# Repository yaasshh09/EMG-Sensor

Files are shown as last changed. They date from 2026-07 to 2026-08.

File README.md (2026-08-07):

## System Overview

The MyoRead is an EMG sensor made up of a four-stage analog circuit that picks up the tiny electrical signals your muscles give off when they contract and cleans them up enough for a computer to read. It's built around the cheap, everyday LM358P op-amp to keep costs down.

```
Forearm electrodes 
      |
      v
[Stage 1] Instrumentation Amplifier   -- 101x gain, rejects common-mode noise
      |
      v
[Stage 2] Twin-T 50 Hz Notch Filter   -- kills UAE mains hum
      |
      v
[Stage 3] Sallen-Key Bandpass 20-500 Hz -- isolates EMG band
      |
      v
[Stage 4] Half-wave rectifier + RC envelope (tau = 47 ms)
```
<p align="center">
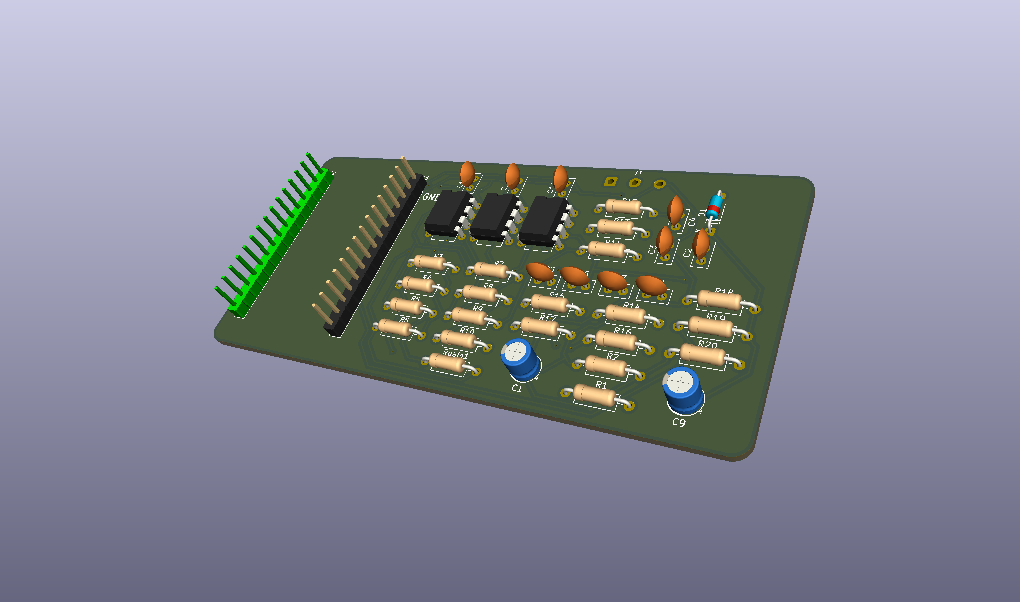
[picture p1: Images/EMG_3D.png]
3D
  
</p>
<p align="center">
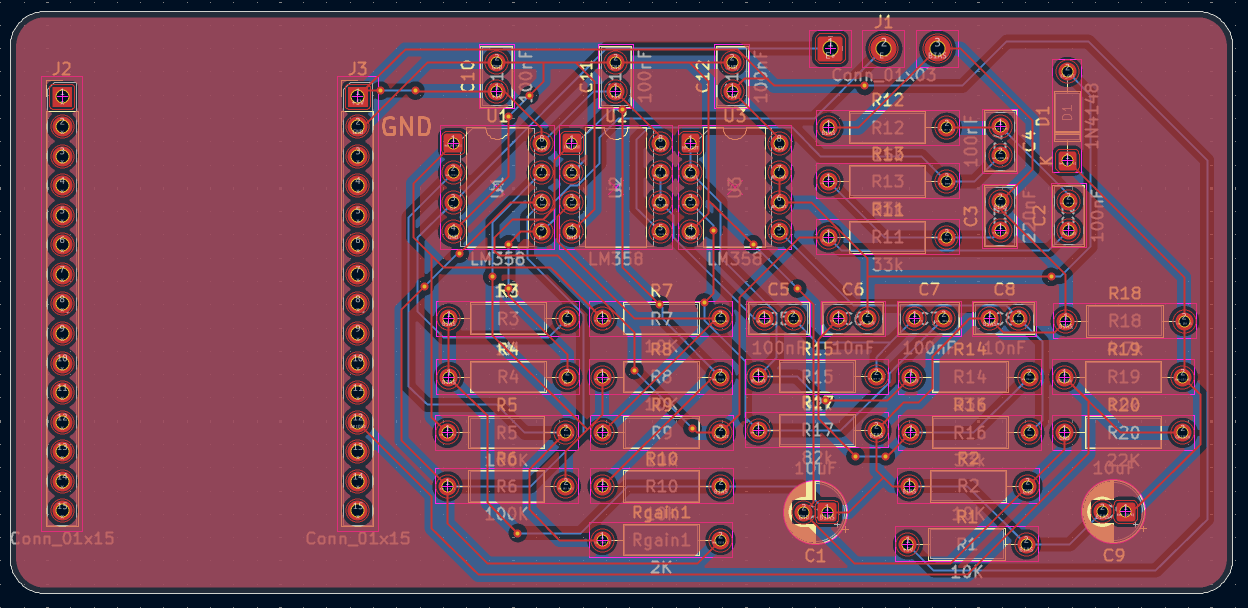
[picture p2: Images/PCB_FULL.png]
FULL
  
</p>
<p align="center">
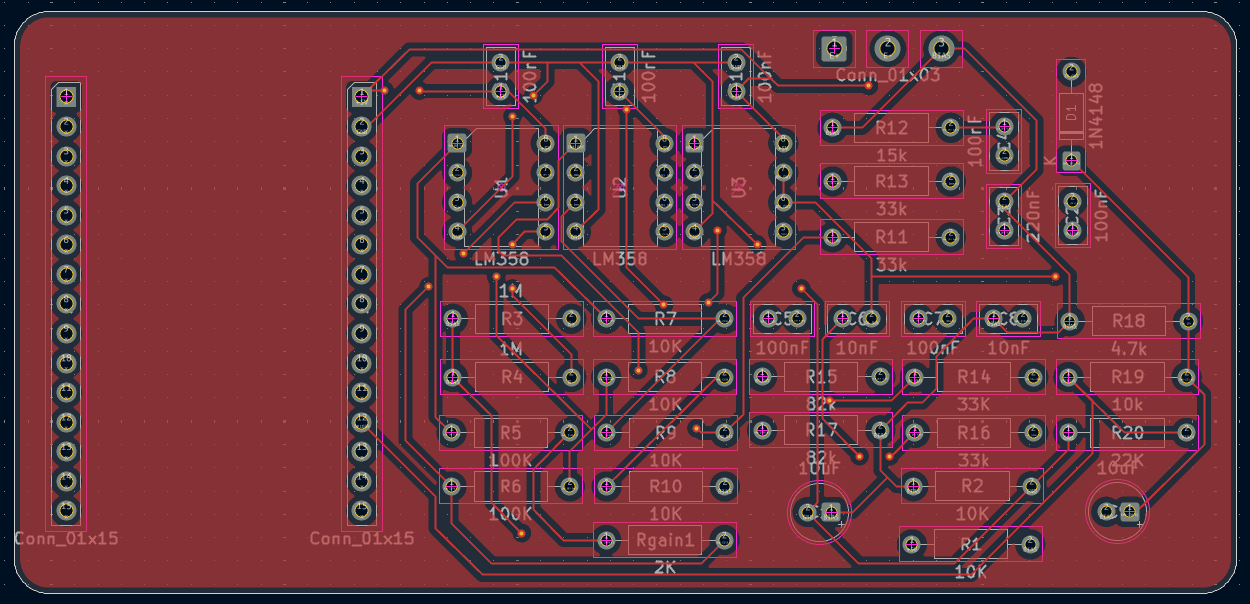
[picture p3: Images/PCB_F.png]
F
  
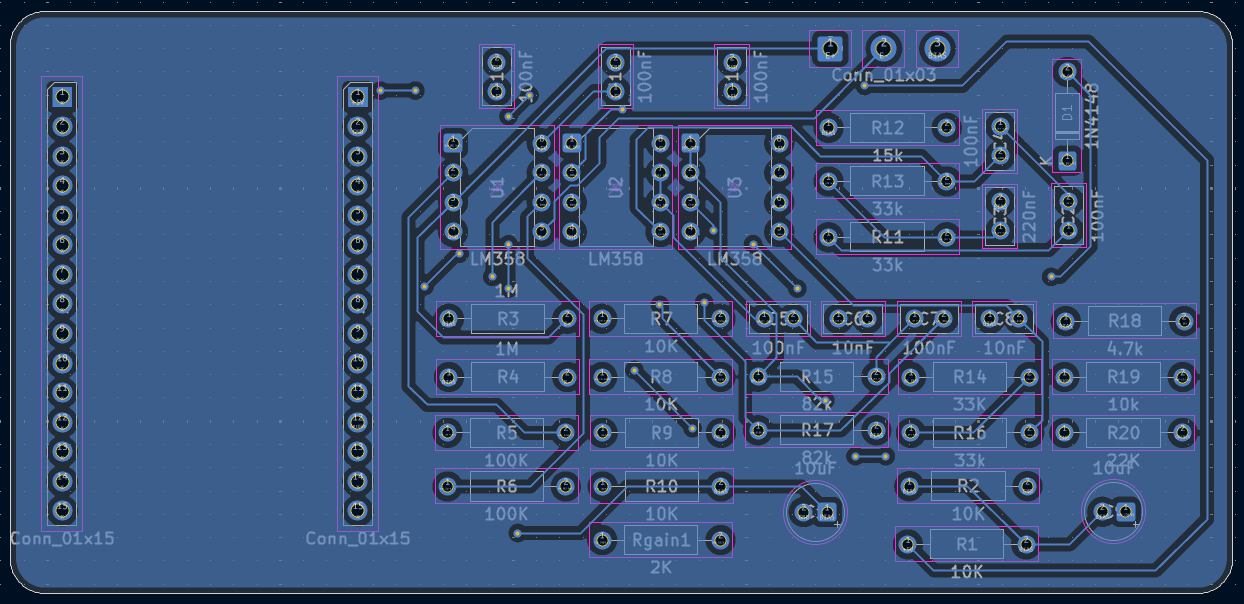
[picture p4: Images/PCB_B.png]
B
 
</p>

## Signal Chain

All op-amp stages use the **LM358P** (DIP-8, single supply 5 V).

The LM358P output swings only 0.05 V to 3.5 V on a 5 V supply. A 2.5 V DC bias is applied at every stage input so the AC signal can swing symmetrically without clipping.

### Stage 0 -- Bias circuit

Two matched 10 kohm resistors from 5 V to GND. Midpoint = 2.5 V.

```
V_bias = 5V x R2 / (R1 + R2) = 5V x 10k / 20k = 2.5 V
```
<p>
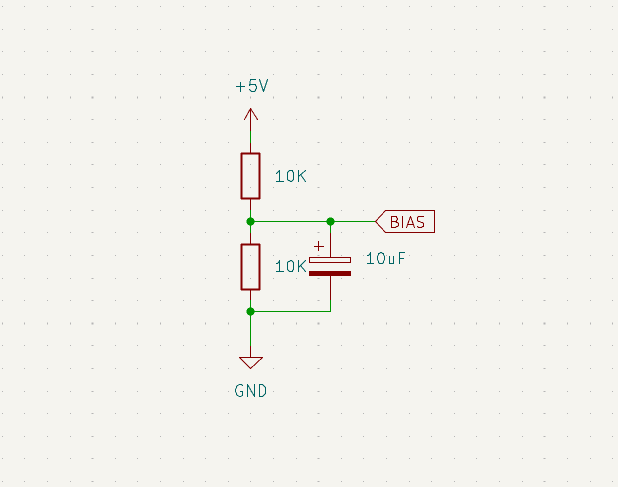
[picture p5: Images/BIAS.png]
   
</p>

### Stage 1 - 3-op-amp instrumentation amplifier

```
Gain = 1 + (2 x Rf / Rg) = 1 + (2 x 100k / 2k) = 101x
```

- Rf = 100 kohm x2 (feedback around OA1, OA2)
- Rg = 2 kohm (single resistor between OA1 IN- and OA2 IN-)
- OA3 difference amplifier: 4 matched 10 kohm resistors

CMRR depends on matching the four OA3 resistors. Select four from the kit using a multimeter: target within 1% of each other.

<p>
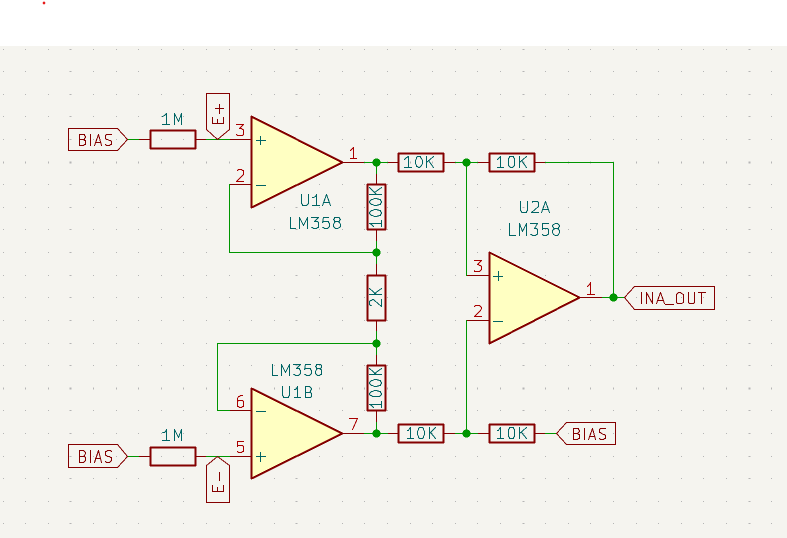
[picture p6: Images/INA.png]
   
</p>

### Stage 2 - Twin-T 50 Hz notch filter

```
f_notch = 1 / (2pi x R x C)
R = 1 / (2pi x 50 x 100nF) = 31.8 kohm --> 33 kohm (E24 standard)
Centre resistor: R/2 = 15 kohm
Centre capacitor: 2C = 220 nF
Actual f_notch with 33 kohm: 48.2 Hz -- effective against 50 Hz hum
```

Followed by a unity-gain op-amp buffer to restore drive capability.

<p>
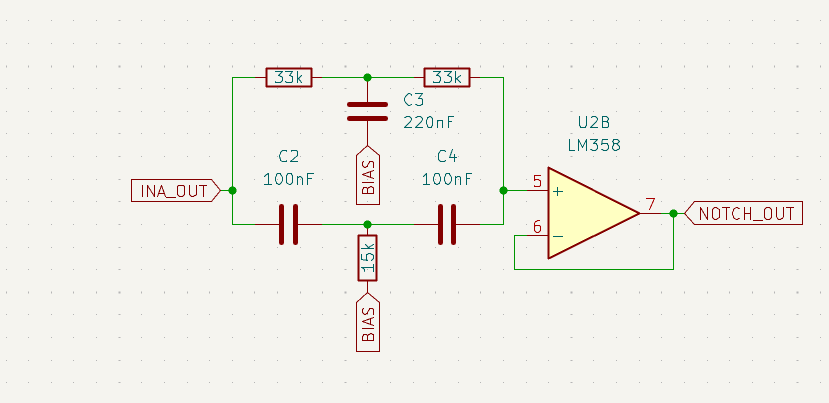
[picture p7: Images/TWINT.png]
   
</p>

### Stage 3 - Sallen-Key bandpass 20-500 Hz

High-pass (20 Hz):
```
C = 100 nF
R = 1 / (2pi x 20 x 100nF) = 79.6 kohm --> 82 kohm
Actual cutoff: 19.4 Hz
```

Low-pass (500 Hz):
```
C = 10 nF
R = 1 / (2pi x 500 x 10nF) = 31.8 kohm --> 33 kohm
Actual cutoff: 482 Hz
```

<p>
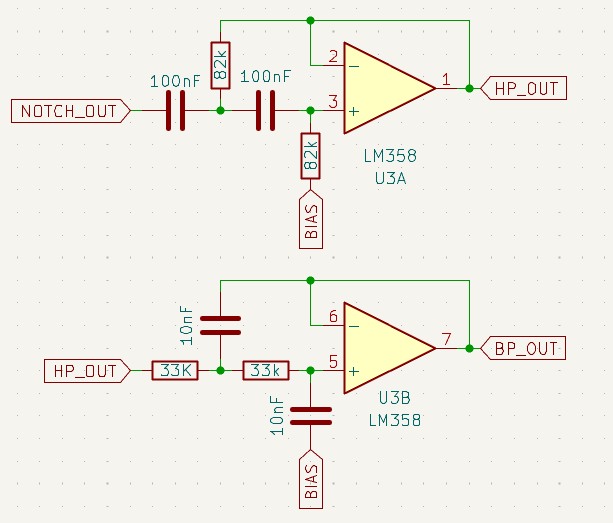
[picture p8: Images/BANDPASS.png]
   
</p>

### Stage 4 - Envelope detector

```
Half-wave rectifier: 1N4148 signal diode (stripe = cathode, faces output)
RC smoother: R = 4.7 kohm, C = 10 uF electrolytic
tau = R x C = 4700 x 0.00001 = 47 ms

Constraint: 1/500Hz = 2ms << tau << 1/20Hz = 50ms  (satisfied)
```
<p>
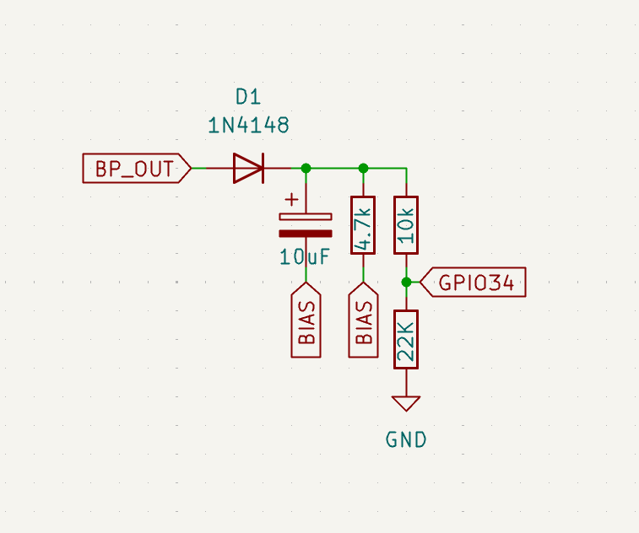
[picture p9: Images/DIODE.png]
   
</p>

The output is a slowly-varying DC voltage proportional to muscle activation level. This feeds directly into your  microcontroller.

## Electrode placement

```
FOREARM (palm facing up, elbow left, wrist right)

+------------------------------------------+
|  ELBOW <----------------------- WRIST    |
|                                          |
|  [IN+]  [IN-]                   [REF]    |
|  2-3 cm apart, over muscle belly  bony   |
|  (inner forearm, palm side)       bump   |
+------------------------------------------+
```

- IN+ and IN- over the forearm flexor muscle belly, 2-3 cm apart along the muscle fibre direction
- REF on the bony wrist prominence (styloid process) -- no muscle underneath, picks up noise only

Skin prep: alcohol wipe, apply conductive gel under each pad. Target skin impedance below 10 kohm between electrodes.

## Bill Of Materials

| Component | Manufacturer Part Number | Description | Quantity | Unit Price | Total Price |
|---|---|---|---:|---:|---:|
| 10 kΩ Resistor | MFR-25FRF52-10K | RES 10K OHM 1% 1/4W AXIAL | 10 | $0.042 | $0.42 |
| 33 kΩ Resistor | MFR-25FTE52-33K | RES 33K OHM 1% 1/4W AXIAL | 10 | $0.042 | $0.42 |
| 1 MΩ Resistor | MFR-25FRF52-1M | RES 1M OHM 1% 1/4W AXIAL | 2 | $0.100 | $0.20 |
| 100 kΩ Resistor | MFR-25FBF52-100K | RES 100K OHM 1% 1/4W AXIAL | 2 | $0.100 | $0.20 |
| 82 kΩ Resistor | MFR-25FBF52-82K | RES 82K OHM 1% 1/4W AXIAL | 2 | $0.100 | $0.20 |
| 15 kΩ Resistor | MFR-25FBF52-15K | RES 15K OHM 1% 1/4W AXIAL | 1 | $0.100 | $0.10 |
| 4.7 kΩ Resistor | MFR-25FTE52-4K7 | RES 4.7K OHM 1% 1/4W AXIAL | 1 | $0.100 | $0.10 |
| 22 kΩ Resistor | MFR-25FTE52-22K | RES 22K OHM 1% 1/4W AXIAL | 1 | $0.100 | $0.10 |
| Signal Diode | 1N4148 | DIODE STANDARD 100V 200MA DO35 | 1 | $0.100 | $0.10 |
| Operational Amplifier | LM358P | IC OPAMP GP 2 CIRCUIT 8DIP | 3 | $0.330 | $0.99 |
| 2 kΩ Resistor | MFR-25FBF52-2K | RES 2K OHM 1% 1/4W AXIAL | 1 | $0.100 | $0.10 |
| 100 nF Ceramic Capacitor | K104K15X7RF5TL2 | CAP CER 0.1UF 50V X7R RADIAL | 10 | $0.167 | $1.67 |
| 10 nF Ceramic Capacitor | A103K15X7RF5TAA | CAP CER 10000PF 50V X7R AXIAL | 2 | $0.260 | $0.52 |
| 10 µF Electrolytic Capacitor | 50YXJ10M5X11 | CAP ALUM 10UF 20% 50V RADIAL TH | 2 | $0.320 | $0.64 |
| 220 nF Ceramic Capacitor | FG14X7R1H224KNT00 | CAP CER 0.22UF 50V X7R RADIAL | 1 | $0.280 | $0.28 |

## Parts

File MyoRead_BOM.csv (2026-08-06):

Index | Manufacturer Part Number | Manufacturer Name | Description | Lead Time | Availability | Stock Status | Attrition % | Requested Quantity 1 | Pack Quantity 1 | Pack Type 1 | Digi-Key Part Number 1 | Unit Price 1 | Extended Price 1 | Minimum Order Quantity 1 | Customer Reference | Requested Part Number | Lead Weeks | Datasheet | Reference Designator | US Import Tariff | Note | Part Status | RoHS Status | REACH Status | Moisture Sensitivity Level (MSL) | ECCN | HTSUS | Country of Origin | Environmental Information | Original Part numbers | Unit of Measure | Image | Product Notes
1 | MFR-25FRF52-10K | YAGEO | RES 10K OHM 1% 1/4W AXIAL |  | 197,132 | In Stock |  | 10 | 10 | Cut Tape (CT) | 13-MFR-25FRF52-10KCT-ND | 0.04200 | $0.42 | 1 |  | 13-MFR-25FRF52-10KCT-ND | 18 | https://yageogroup.com/content/Resource%20Library/Datasheet/YAGEO-MFR_DATASHEET.pdf |  | May apply on shipments to the U.S. |  | Active | ROHS3 Compliant | REACH Unaffected | Not Applicable | EAR99 | 8533.21.0090 | Taiwan |  | 13-MFR-25FRF52-10KCT-ND | Each | https://mm.digikey.com/Volume0/opasdata/d220001/derivates/6/002/365/910/MFR-25FRF52-10K_web%28640x640%29.jpg
2 | MFR-25FTE52-33K | YAGEO | RES 33K OHM 1% 1/4W AXIAL |  | 4,576 | In Stock |  | 10 | 10 | Cut Tape (CT) | 13-MFR-25FTE52-33KCT-ND | 0.04200 | $0.42 | 1 |  | 13-MFR-25FTE52-33KCT-ND | 18 | https://yageogroup.com/content/Resource%20Library/Datasheet/YAGEO-MFR_DATASHEET.pdf |  | May apply on shipments to the U.S. |  | Active | ROHS3 Compliant | REACH Unaffected | Not Applicable | EAR99 | 8533.21.0090 | Taiwan |  | 13-MFR-25FTE52-33KCT-ND | Each | https://mm.digikey.com/Volume0/opasdata/d220001/medias/images/2467/33k-Ohm-Axial-1%25-MFR.jpg
3 | MFR-25FRF52-1M | YAGEO | RES 1M OHM 1% 1/4W AXIAL |  | 10,756 | In Stock |  | 2 | 2 | Cut Tape (CT) | 13-MFR-25FRF52-1MCT-ND | 0.10000 | $0.20 | 1 |  | 13-MFR-25FRF52-1MCT-ND | 18 | https://yageogroup.com/content/Resource%20Library/Datasheet/YAGEO-MFR_DATASHEET.pdf |  | May apply on shipments to the U.S. |  | Active | ROHS3 Compliant | REACH Unaffected | Not Applicable | EAR99 | 8533.21.0090 | Taiwan |  | 13-MFR-25FRF52-1MCT-ND | Each | https://mm.digikey.com/Volume0/opasdata/d220001/derivates/6/002/449/103/MFR-25FRF52-1M_web%28640x640%29.jpg
4 | MFR-25FBF52-100K | YAGEO | RES 100K OHM 1% 1/4W AXIAL |  | 28,752 | In Stock |  | 2 | 2 | Bulk | 100KXBK-ND | 0.10000 | $0.20 | 1 |  | 100KXBK-ND | 18 | https://yageogroup.com/content/Resource%20Library/Datasheet/YAGEO-MFR_DATASHEET.pdf |  | May apply on shipments to the U.S. |  | Active | ROHS3 Compliant | REACH Unaffected | Not Applicable | EAR99 | 8533.21.0090 | China |  | 100KXBK-ND | Each | https://mm.digikey.com/Volume0/opasdata/d220001/derivates/6/002/475/045/MFR-25FRF52-100K_web%28640x640%29.jpg
5 | MFR-25FBF52-82K | YAGEO | RES 82K OHM 1% 1/4W AXIAL |  | 12,381 | In Stock |  | 2 | 2 | Bulk | 13-MFR-25FBF52-82K-ND | 0.10000 | $0.20 | 1 |  | 13-MFR-25FBF52-82K-ND | 18 | https://yageogroup.com/content/Resource%20Library/Datasheet/YAGEO-MFR_DATASHEET.pdf |  | N/A |  | Active | ROHS3 Compliant | REACH Unaffected | Not Applicable | EAR99 | 8533.21.0090 | Taiwan |  | 13-MFR-25FBF52-82K-ND | Each | https://mm.digikey.com/Volume0/opasdata/d220001/medias/images/2460/82k-Ohm-Axial-1%25-MFR.jpg
6 | MFR-25FBF52-15K | YAGEO | RES 15K OHM 1% 1/4W AXIAL | 1 past due; estimated in-stock on 20-Jul-2026 | 0 | Normally Stocking |  | 1 | 1 | Bulk | 15.0KXBK-ND | 0.10000 | $0.10 | 1 |  | 15.0KXBK-ND | 18 | https://yageogroup.com/content/Resource%20Library/Datasheet/YAGEO-MFR_DATASHEET.pdf |  | May apply on shipments to the U.S. |  | Active | ROHS3 Compliant | REACH Unaffected | Not Applicable | EAR99 | 8533.21.0090 | China |  | 15.0KXBK-ND | Each | https://mm.digikey.com/Volume0/opasdata/d220001/derivates/6/002/233/244/MFR-25FRF52-15K_web%28640x640%29.jpg
7 | MFR-25FTE52-4K7 | YAGEO | RES 4.7K OHM 1% 1/4W AXIAL |  | 3,565 | In Stock |  | 1 | 1 | Cut Tape (CT) | 13-MFR-25FTE52-4K7CT-ND | 0.10000 | $0.10 | 1 |  | 13-MFR-25FTE52-4K7CT-ND | 18 | https://yageogroup.com/content/Resource%20Library/Datasheet/YAGEO-MFR_DATASHEET.pdf |  | May apply on shipments to the U.S. |  | Active | ROHS3 Compliant | REACH Unaffected | Not Applicable | EAR99 | 8533.21.0090 | Taiwan |  | 13-MFR-25FTE52-4K7CT-ND | Each | https://mm.digikey.com/Volume0/opasdata/d220001/derivates/6/002/645/569/4%2C7k-Ohm-Axial-1%25-MFR_web%28640x640%29.jpg
8 | MFR-25FTE52-22K | YAGEO | RES 22K OHM 1% 1/4W AXIAL |  | 502 | In Stock |  | 1 | 1 | Cut Tape (CT) | 13-MFR-25FTE52-22KCT-ND | 0.10000 | $0.10 | 1 |  | 13-MFR-25FTE52-22KCT-ND | 18 | https://yageogroup.com/content/Resource%20Library/Datasheet/YAGEO-MFR_DATASHEET.pdf |  | May apply on shipments to the U.S. |  | Active | ROHS3 Compliant | REACH Unaffected | Not Applicable | EAR99 | 8533.21.0090 | Taiwan |  | 13-MFR-25FTE52-22KCT-ND | Each | https://mm.digikey.com/Volume0/opasdata/d220001/derivates/6/002/642/617/22k-Ohm-Axial-1%25-MFR_web%28640x640%29.jpg
9 | 1N4148 | onsemi | DIODE STANDARD 100V 200MA DO35 |  | 913,107 | In Stock |  | 1 | 1 | Bulk | 1N4148FS-ND | 0.10000 | $0.10 | 1 |  | 1N4148FS-ND | 62 | https://www.onsemi.com/pub/Collateral/1N914-D.PDF |  | May apply on shipments to the U.S. |  | Active | ROHS3 Compliant | REACH Unaffected | Not Applicable | EAR99 | 8541.10.0070 | China | https://www.onsemi.com/site/pdf/RoHS-statement.pdf|https://www.onsemi.com/PowerSolutions/MaterialComposition.do?export=pdf&opnId=1N4148 | 1N4148FS-ND | Each | https://mm.digikey.com/Volume0/opasdata/d220001/medias/images/649/1N5229BFS.jpg
10 | LM358P | Texas Instruments | IC OPAMP GP 2 CIRCUIT 8DIP |  | 33,767 | In Stock |  | 3 | 3 | Tube | 296-1395-5-ND | 0.33000 | $0.99 | 1 |  | 296-1395-5-ND | 16 | https://www.ti.com/general/docs/suppproductinfo.tsp?distId=10 |  | May apply on shipments to the U.S. |  | Active | ROHS3 Compliant | REACH Unaffected | Not Applicable | EAR99 | 8542.33.0001 | China |  | 296-1395-5-ND | Each | https://mm.digikey.com/Volume0/opasdata/d220001/medias/images/6222/296%7E4040082%7EP%7E8.jpg
11 | MFR-25FBF52-2K | YAGEO | RES 2K OHM 1% 1/4W AXIAL |  | 9,476 | In Stock |  | 1 | 1 | Bulk | 2.00KXBK-ND | 0.10000 | $0.10 | 1 |  | 2.00KXBK-ND | 18 | https://yageogroup.com/content/Resource%20Library/Datasheet/YAGEO-MFR_DATASHEET.pdf |  | May apply on shipments to the U.S. |  | Active | ROHS3 Compliant | REACH Unaffected | Not Applicable | EAR99 | 8533.21.0090 | China |  | 2.00KXBK-ND | Each | https://mm.digikey.com/Volume0/opasdata/d220001/derivates/6/002/298/338/MFR-25FRF52-2K_web%28640x640%29.jpg
12 | K104K15X7RF5TL2 | Vishay Beyschlag/Draloric/BC Components | CAP CER 0.1UF 50V X7R RADIAL |  | 224,231 | In Stock |  | 10 | 10 | Cut Tape (CT) | BC1084CT-ND | 0.16700 | $1.67 | 1 |  | BC1084CT-ND | 18 | https://www.vishay.com/docs/45171/kseries.pdf |  | May apply on shipments to the U.S. |  | Active | ROHS3 Compliant | REACH Unaffected | Not Applicable | EAR99 | 8532.24.0060 | China | https://www.vishay.com/en/quality/ | BC1084CT-ND | Each | https://mm.digikey.com/Volume0/opasdata/d220001/medias/images/4847/56_K102K15X7RF5TL2.jpg
13 | A103K15X7RF5TAA | Vishay Beyschlag/Draloric/BC Components | CAP CER 10000PF 50V X7R AXIAL |  | 135,945 | In Stock |  | 2 | 2 | Cut Tape (CT) | 1103PHCT-ND | 0.26000 | $0.52 | 1 |  | 1103PHCT-ND | 18 | https://www.vishay.com/docs/45164/aseries.pdf |  | May apply on shipments to the U.S. |  | Active | ROHS3 Compliant | REACH Unaffected | Not Applicable | EAR99 | 8532.24.0040 | China |  | 1103PHCT-ND | Each | https://mm.digikey.com/Volume0/opasdata/d220001/medias/images/591/A152K15X7RF5TAA.jpg
14 | 50YXJ10M5X11 | Rubycon | CAP ALUM 10UF 20% 50V RADIAL TH |  | 30,784 | In Stock |  | 2 | 2 | Bulk | 1189-2322-ND | 0.32000 | $0.64 | 1 |  | 1189-2322-ND | 31 | https://www.rubycon.co.jp/wp-content/uploads/catalog-aluminum/YXJ.pdf |  | May apply on shipments to the U.S. |  | Active | ROHS3 Compliant | REACH Unaffected | Not Applicable | EAR99 | 8532.22.0020 | Indonesia | https://mm.digikey.com/Volume0/opasdata/d220001/medias/docus/8961/Rubycon%20CA%20Prop%2065%20Statement.pdf | 1189-2322-ND | Each | https://mm.digikey.com/Volume0/opasdata/d220001/derivates/6/002/682/321/YXJ%20Series%205x11_web%28640x640%29.jpg
15 | FG14X7R1H224KNT00 | TDK | CAP CER 0.22UF 50V X7R RADIAL |  | 5,631 | In Stock |  | 1 | 1 | Bulk | 445-181223-ND | 0.28000 | $0.28 | 1 |  | 445-181223-ND | 24 | https://product.tdk.com/en/system/files/dam/doc/product/capacitor/ceramic/lead-mlcc/catalog/leadmlcc_halogenfree_fg_en.pdf |  | May apply on shipments to the U.S. |  | Active | ROHS3 Compliant | REACH Unaffected | Not Applicable | EAR99 | 8532.24.0060 | China | https://product.tdk.com/en/environment/index.html | 445-181223-ND | Each | https://mm.digikey.com/Volume0/opasdata/d220001/derivates/6/002/328/068/FG28_Type_web%28640x640%29.jpg

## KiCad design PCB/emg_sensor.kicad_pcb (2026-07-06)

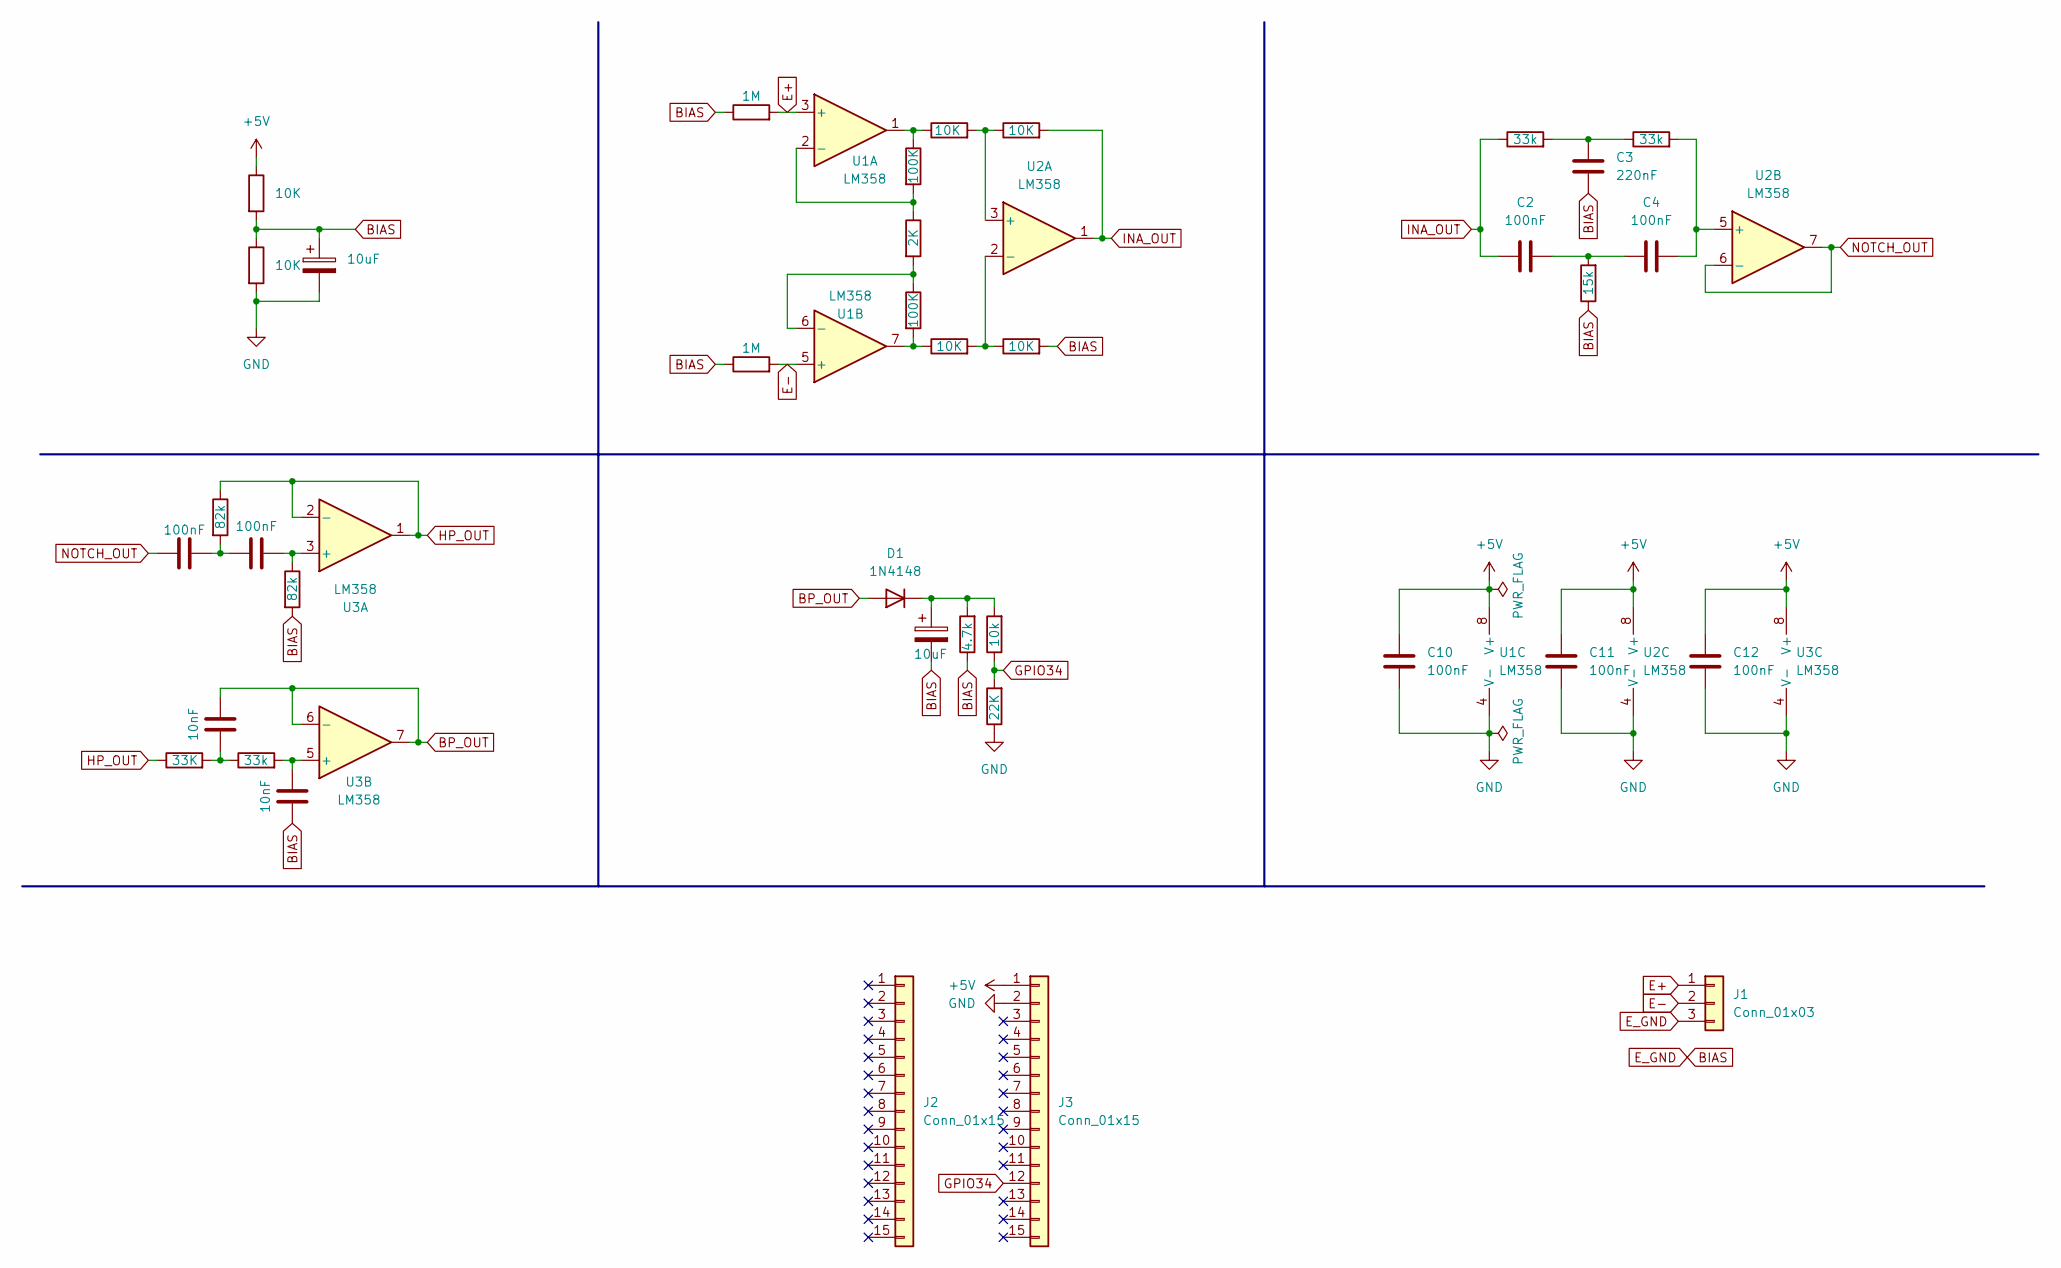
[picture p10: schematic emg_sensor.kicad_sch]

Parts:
C1, C9: 10uF; CP_Radial_D5.0mm_P2.00mm
C2, C4, C5, C7, C10, C11, C12: 100nF; C_Disc_D5.0mm_W2.5mm_P2.50mm
C3: 220nF; C_Disc_D5.0mm_W2.5mm_P2.50mm
C6, C8: 10nF; C_Disc_D5.0mm_W2.5mm_P2.50mm
D1: 1N4148; D_DO-35_SOD27_P7.62mm_Horizontal
J1: Conn_01x03; SolderWire-0.5sqmm_1x03_P4.6mm_D0.9mm_OD2.1mm
J2, J3: Conn_01x15; PinHeader_1x15_P2.54mm_Vertical
R1, R2, R7, R8, R9, R10: 10K; R_Axial_DIN0207_L6.3mm_D2.5mm_P10.16mm_Horizontal
R3, R4: 1M; R_Axial_DIN0207_L6.3mm_D2.5mm_P10.16mm_Horizontal
R5, R6: 100K; R_Axial_DIN0207_L6.3mm_D2.5mm_P10.16mm_Horizontal
R11, R13, R16: 33k; R_Axial_DIN0207_L6.3mm_D2.5mm_P10.16mm_Horizontal
R12: 15k; R_Axial_DIN0207_L6.3mm_D2.5mm_P10.16mm_Horizontal
R14: 33K; R_Axial_DIN0207_L6.3mm_D2.5mm_P10.16mm_Horizontal
R15, R17: 82k; R_Axial_DIN0207_L6.3mm_D2.5mm_P10.16mm_Horizontal
R18: 4.7k; R_Axial_DIN0207_L6.3mm_D2.5mm_P10.16mm_Horizontal
R19: 10k; R_Axial_DIN0207_L6.3mm_D2.5mm_P10.16mm_Horizontal
R20: 22K; R_Axial_DIN0207_L6.3mm_D2.5mm_P10.16mm_Horizontal
Rgain1: 2K; R_Axial_DIN0207_L6.3mm_D2.5mm_P10.16mm_Horizontal
U1, U2, U3: LM358; DIP-8_W7.62mm

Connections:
+5V: C10.1, C11.1, C12.1, J3.1, R1.1, U1.8 (V+), U2.8 (V+), U3.8 (V+)
BIAS: C1.1, C3.2, C8.1, C9.2, J1.3, R1.2, R2.1, R3.1, R4.1, R10.2, R12.1, R17.2, R18.1
BP_OUT: C6.2, D1.2 (A), U3.6 (-), U3.7
E+: J1.1, R3.2, U1.3 (+)
E-: J1.2, R4.2, U1.5 (+)
GND: C1.2, C10.2, C11.2, C12.2, J3.2, R2.2, R20.1, U1.4 (V-), U2.4 (V-), U3.4 (V-)
GPIO34: J3.12, R19.1, R20.2
HP_OUT: R14.1, R15.1, U3.1, U3.2 (-)
INA_OUT: C2.1, R9.2, R11.1, U2.1
NOTCH_OUT: C5.1, U2.6 (-), U2.7
unnamed: C2.2, C4.1, R12.2
unnamed: C3.1, R11.2, R13.1
unnamed: C5.2, C7.1, R15.2
unnamed: C6.1, R14.2, R16.1
unnamed: C9.1, D1.1 (K), R18.2, R19.2
unnamed: R5.1, R7.1, U1.1
unnamed: R6.2, R8.1, U1.7
unnamed: R5.2, Rgain1.1, U1.2 (-)
unnamed: R6.1, Rgain1.2, U1.6 (-)
unnamed: R7.2, R9.1, U2.3 (+)
unnamed: R8.2, R10.1, U2.2 (-)
unnamed: C4.2, R13.2, U2.5 (+)
unnamed: C7.2, R17.1, U3.3 (+)
unnamed: C8.2, R16.2, U3.5 (+)

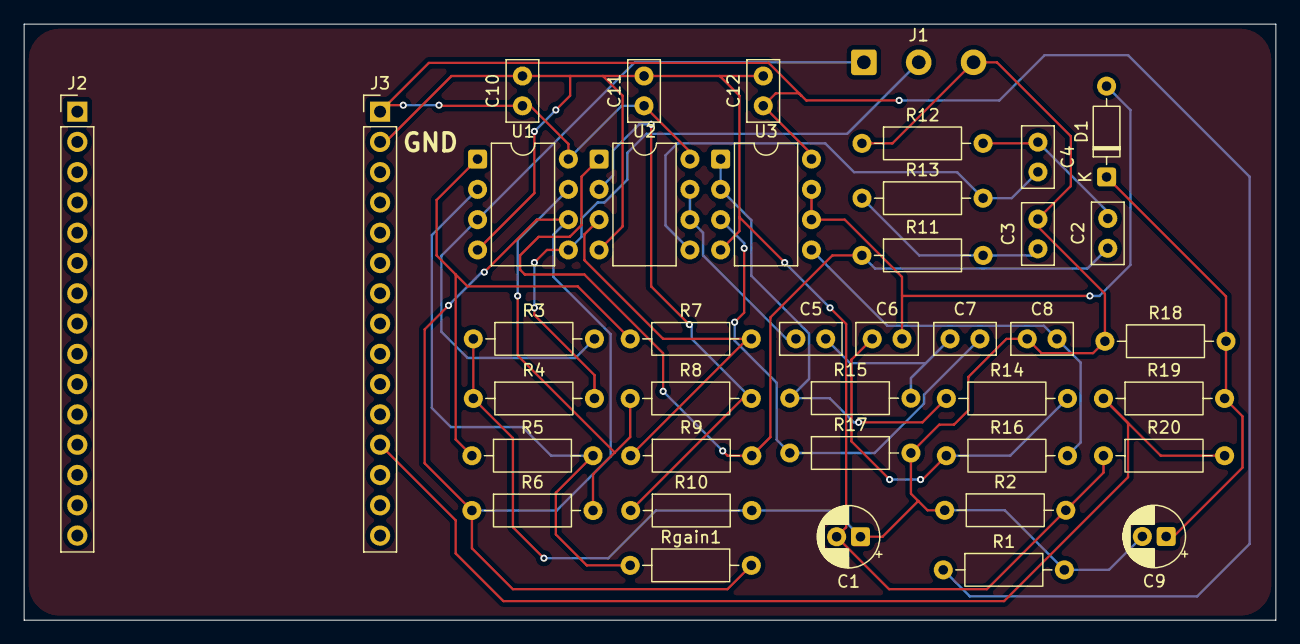
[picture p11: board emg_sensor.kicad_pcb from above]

Board: 2 copper layers, 105.0 x 50.0 mm, 40 parts (0 on the bottom side), 24 nets.

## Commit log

2026-07-06 First commit, hardware only
    [emg_sensor.kicad_pcb, emg_sensor.kicad_sch, emg_signal.kicad_pcb_bom.csv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]
2026-07-06 fix readme layout and rebuild index
    [emg_sensor.kicad_pcb, emg_sensor.kicad_sch, emg_signal.kicad_pcb_bom.csv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]
2026-07-28 Added clearer .csv
    [MyoRead_BOM.csv]
2026-08-05 Enhance README with more PCB and 3D images
    Added additional images to the README for better visualization.
2026-08-06 Hopefully Final Changes
    [MyoRead.csv, MyoRead_BOM.csv]
2026-08-06 Corrected BOM
    [MyoRead_BOM.csv]
